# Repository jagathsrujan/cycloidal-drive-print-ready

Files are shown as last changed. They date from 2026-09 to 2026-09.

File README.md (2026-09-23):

# Cycloidal Drive — Print-Ready

A 15:1 cycloidal gearbox, cleaned up in FreeCAD and exported for 3D printing.
**106 printed parts across 15 part types**, plus the purchased hardware sorted out.

The design is the [HowToMechatronics DIY Cycloidal Drive](https://howtomechatronics.com/how-it-works/what-is-cycloidal-driver-designing-3d-printing-and-testing/)
(N = 16 ring pins, R = 45 mm, Rr = 6.5 mm, E = 1.5 mm). This repo is the print-prep pass
over that CAD: the original STEP is a single flat assembly of 216 objects with no indication
of what is printable, what you have to buy, or how many of each to make.

## How it works

An eccentric cam on the input shaft drives two cycloidal disks around the inside of a ring of
16 rollers. The disk has **one fewer lobe than there are rollers** — 15 lobes against 16 rollers —
so one full turn of the cam advances the disk by exactly one lobe. That single rule gives the
whole gear ratio:

```
ratio = N / (N - 1) = 16 / 15  ->  15:1 reduction
```

Two disks run 180° out of phase to cancel the imbalance the eccentric motion creates. The
reduced rotation leaves through 6 output pins passing through holes in both disks.

The design parameters, from the article:

| | |
|---|---|
| `N` rollers | 16 |
| `R` roller pitch radius | 45 mm |
| `Rr` roller radius | 6.5 mm |
| `E` eccentricity | 1.5 mm |
| Ratio | 15:1 |
| Envelope | Ø115 mm, 109 mm long including the NEMA 17 |

The disk profile is an epitrochoid, not a circle arc — `R/(E·N)` is what shapes the lobes, and
`E` must stay below half the roller diameter or the profile folds on itself. The roller "teeth"
are ball bearings rather than printed bushings; that substitution is the whole reason a printed
version of this gearbox survives at all.

Measured on the author's build: **260 N·cm out of the gearbox from a 26 N·cm NEMA 17** — about
10× torque multiplication, roughly 66 % efficiency. It is also back-drivable.

## What's here

| Path | What it is |
|---|---|
| `Cycloidal Drive - PRINT READY.FCStd` | cleaned FreeCAD model, parts grouped and named |
| `STL/01_PRINT_THESE/` | 15 folders, one per printed part, quantity in the folder name |
| `3MF_PRINT_READY/` | the whole drive as 5 ready-to-slice Bambu projects, P1S and H2D |
| `STL/PRINT_LIST.md` | print list, buy list, slicer settings |
| `BOM.md` | hardware buy list with prices, sources, and CAD fit checks |
| `ASSEMBLY.md` | build order, verified stack heights, and the gotchas |
| `Cycloidal Drive - 3D Printable DIY.STEP` | the original author's CAD, unmodified |

## Print it without slicing

`3MF_PRINT_READY/` carries the whole drive as Bambu Studio projects, split for a P1S and an H2D.
The split differs by machine, not by part: the H2D's bed takes the motor mount and coupler onto
its structural plate, so the same 106 parts make two projects there and three on the P1S.

| Project | Covers |
|---|---|
| `H2D_01_structural.3mf` | housing, lid, both disks, both output flanges, 4 shaft sections, motor mount, coupler |
| `H2D_02_smallparts.3mf` | 16 ring pins, 6 output pins, 32 × 7 mm + 16 × 3 mm spacers, 6 rings, 18 shims |
| `P1S_01_bigdiscs.3mf` | housing, lid, both disks, both output flanges |
| `P1S_02_shaftparts.3mf` | 4 shaft sections, motor mount, coupler |
| `P1S_03_smallparts.3mf` | the small parts, same 85 as the H2D's second plate |

They are unsliced, and the parts are **not arranged yet** — every object is stacked at the plate
centre, so the first thing to do after opening one is Arrange (or the model prints as a tower).
Nothing has a saved plate time either; slice once to get the real number.

What is already set is the profile, exactly what this repo asks for — **0.07 mm hole / 0.02 mm
contour expansion**, 0.2 mm layers, 5 walls, no supports, 50 % gyroid on the big parts and 100 %
grid with an auto brim on the small ones, Bambu PLA Basic on the High Temp plate. So skip the
calibration plate if you print these on a Bambu with that filament; calibrate if your setup differs.

## Print quantities

| Qty | Part | | Qty | Part |
|----:|---|-|----:|---|
| 1 | Roller Pins Housing | | 16 | Ring Pin Ø6×35 |
| 1 | Housing Lid | | 6 | Output Pin Ø6×15 |
| 2 | Cycloidal Disk | | 32 | Spacer 7 mm |
| 4 | Input Shaft (sections p1–p4) | | 16 | Spacer 3 mm |
| 1 | Output Flange Front (13 mm) | | 6 | Distance Ring 3×6 |
| 1 | Output Flange Rear (16 mm) | | 12 | Shim 1 mm × Ø6 |
| 1 | Motor Coupler | | 6 | Shim 1 mm × Ø15 |
| 1 | Motor Mount (NEMA 17) | | | |

## Buy these

44 × bearing 686-2RS (6×13×5) · 4 × 6802-2RS (15×24×5) · 2 × 6807-2RS (35×47×7) ·
1 × NEMA 17 stepper · M3/M4 bolts and heat-set threaded inserts — full quantities in
[`STL/PRINT_LIST.md`](STL/PRINT_LIST.md).

## Before you print

Not slicing it from the STLs? The `3MF_PRINT_READY/` projects already carry the settings below.

Set **Hole Horizontal Expansion ≈ 0.07 mm** in your slicer. Printed bores come out undersize,
and that setting is what makes the 13 mm and 24 mm bearing seats press-fit instead of either
loose or impossible. Calibrate on a test plate first.

The 16 ring pins are the only printed part taking real load. They print hollow with a 3 mm bore
on purpose — the article's build slid **3 mm metal shafts** through them, and Ø6 mm ground steel
dowel is a straight drop-in upgrade if you'd rather not print them at all. See
[`ASSEMBLY.md`](ASSEMBLY.md) for the build order and the fits that will bite you.

## Model structure

The FreeCAD file groups everything the way you'd work through it at the printer:

```
Cycloidal Drive - PRINT READY
├── 01_PRINT_THESE_3D          (15 groups, 106 parts — x{N}_{name})
└── 02_BUY_THESE_HARDWARE      (11 groups, 92 parts)
```

Geometry is untouched — every part sits exactly where it did in the original assembly, so
clearances and fits are unchanged. Only the organisation, names and visibility are new.

## Credit

Original design and CAD by [HowToMechatronics](https://howtomechatronics.com/how-it-works/what-is-cycloidal-driver-designing-3d-printing-and-testing/).
The STEP file is redistributed here unmodified for reference; check the original source for
its terms before reusing the CAD commercially.

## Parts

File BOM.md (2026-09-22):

# BOM — Hardware Buy List

Everything to buy for one complete gearbox (the 106 printed parts are not included — see
[`STL/PRINT_LIST.md`](STL/PRINT_LIST.md)). Prices in ₹, checked Sep 2026. **Every dimension
below was measured against `Cycloidal Drive - PRINT READY.FCStd`** — the hardware group and
every mating bore in the printed parts — so the sizes are known-good, not assumed.

## Order 1 — OnlyScrews (onlyscrews.in)

| Qty | Item | Unit ₹ | Line ₹ | Notes |
|----:|---|---:|---:|---|
| 44 | 686 ZZ bearing 6×13×5 | 26.00 | 1,144.00 | 32 ring rollers + 12 output-pin bearings. CAD: Ø6 bore / Ø13 OD / 5.00 wide, stack heights 27 and 15 mm — exact |
| 4 | M3×8 socket head SS304 DIN 912 | 3.20 | 12.80 | motor → mount. Mount has the 31×31 pattern, holes measured at exactly ±15.5 |
| 4 | M3×10 socket head SS304 DIN 912 | 3.20 | 12.80 | mount → housing. Housing holes measured at exactly the 63×26 rectangle (±31.5, ±13) |
| 6 | M3×20 button head SS304 * | 2.60 | 15.60 | output roller pins (span X 93–116 in CAD). *socket head is out of stock — button head fits; socket head ₹3.80 when restocked |
| 2 | M3×30 socket head SS304 DIN 912 | 6.00 | 12.00 | clamps the 4 input-shaft sections; threads into the 2 shaft inserts (X 87–120 measured) |
| 8 | M4×40 socket head SS304 DIN 912 | 7.60 | 60.80 | housing ↔ lid. Lid has Ø4 clearance + Ø7×4 head counterbore; 40 mm shank lands exactly on the insert |
| 9 | M3×5 brass heat-set insert (3D-printing slant knurled) | 4.60 | 41.40 | output face ×6 (Ø4×5 pockets), shaft back ×2, coupler ×1. OD 4.4 vs Ø4.0 holes = correct heat-set bite. **Use 5 mm, not 6 mm — the output-face pockets are exactly 5 deep** |
| 8 | M4×6 brass heat-set insert | 3.40 | 27.20 | housing back face. CAD pocket Ø5.6 × 5–6 deep; insert OD 5.8 × 6 → fits. **Do not buy the 8 mm version — it bottoms out and sticks out** |
| 16 | M3×35 hard dowel pin (3 mm metal shaft) | 6.40 | 102.40 | slides inside the printed hollow ring pins (bore Ø3.0 × 34.8 measured) |

**Subtotal ₹1,429.00** + 18 % GST at checkout. Free shipping over ₹799.
Coupon codes seen on site: `DEEZNUTS` 5 % over ₹849 · `SCREWME10` 10 % over ₹1,599 · `LOYALSCREWER` 15 % over ₹2,999.

## Order 2 — bearings + motor (OnlyScrews doesn't stock these)

| Qty | Item | Unit ₹ | Line ₹ | Source |
|----:|---|---:|---:|---|
| 4 | 6802 bearing 15×24×5 | 80.00 | 320.00 | IndiaMART — Manzil Trading, Mumbai. CAD: Ø15 journals on all 4 shaft sections, Ø24 bores in front flange + both disks + rear flange — exact |
| 2 | 6807 bearing 35×47×7 | 98.00 | 196.00 | IndiaMART — Manzil Trading, Mumbai. CAD: Ø47 × 7 seats in housing (X 85–92) and lid (119–126), Ø35 journals on both output flanges — exact |
| 1 | NEMA 17 stepper, 42-40 body, 4.2 kg-cm, Ø5 D-shaft | 549.00 | 549.00 | Amazon.in (alt: QuartzComponents ₹605). CAD mount = 31×31 + Ø22 pilot + Ø5 × 15 coupler bore — matches any standard 42-40 NEMA 17 |

**Subtotal ₹1,065.00** (IndiaMART prices typically +GST).

## Total

| | ₹ |
|---|---:|
| OnlyScrews (incl. 18 % GST) | 1,686 |
| Bearings (incl. 18 % GST) | 609 |
| Motor | 549 |
| **Total** | **≈ 2,845** |

Variants:
- Listed prices without GST: ₹2,497.
- All-online convenience route (Flipkart ZMS 6802 10-pack ₹1,499 + Amazon XERFU 6807 4-pack ₹400 instead of IndiaMART): ≈ ₹4,140.
- Optional spares (PRINT_LIST recommends): +4 × 686 bearing ≈ +₹123.

## CAD fit checks that mattered

- **686 / 6802 / 6807** measured bore-for-bore against the model: ring roller bores Ø13, output
  stack 1+5+3+5+1 = 15 mm, 6802 journals Ø15 / bores Ø24, 6807 seats Ø47 × 7 / journals Ø35.
  All exact. 686 ZZ vs the CAD's 686-2RS: same dimensions (shield vs seal), fine here.
- **M4/M3 insert lengths** were the one real trap: the CAD models the inserts as Ø5.6 × 5 (M4)
  and Ø4.0 × 5 (M3) in 5–6 mm deep pockets. Buy the 6 mm M4 and the 5 mm M3 — the longer
  versions from the first draft of this BOM would not seat.
- **Coupler insert pocket is Ø5.6** (larger than the insert) — a standard M3 heat-set insert
  sits loose there; add a drop of CA glue.
- **M3 bolts are DIN 912 socket heads** in the model (Ø5.5 head); SS304 socket heads from
  OnlyScrews are the same standard. The M3×20 button-head substitute only changes head height
  inside a counterbore that has clearance to spare.
- **3 mm shafts:** the ring pins print with a Ø3 bore and the CAD expects a 35 mm shaft — the
  M3×35 dowel pins are the OnlyScrews-friendly version of the article's "3 mm metal shaft".

## Links

- onlyscrews.in — [686 ZZ](https://onlyscrews.in/products/686-zz-deep-groove-ball-bearing-6x13x5) ·
  [M3 socket heads](https://onlyscrews.in/collections/socket-head-m3) ·
  [M4×40](https://onlyscrews.in/products/m4-x-40mm-hex-allen-socket-head-ss-304-screw-dia-4mm-length-40mm) ·
  [M3×5 inserts](https://onlyscrews.in/products/m3-x-5mm-3d-printing-brass-threaded-inserts-dia-3mm-length-5mm) ·
  [M4×6 inserts](https://onlyscrews.in/products/m4-x-6mm-brass-threaded-inserts) ·
  [M3×35 dowel pins](https://onlyscrews.in/products/m3-x-35mm-hard-dowel-pins-dia-3mm-length-35mm)
- [IndiaMART 6802 (Manzil Trading)](https://www.indiamart.com/proddetail/6802-zz-2rs-radial-deep-groove-ball-bearing-24685559033.html) ·
  [IndiaMART 6807](https://www.indiamart.com/proddetail/6807-zz-2rs-radial-deep-groove-ball-bearing-24685567673.html)
- [Amazon 6807 4-pack (alt)](https://www.amazon.in/XERFU-6807-ZZ-Pieces-Bearing/dp/B0HDR91JZ7) ·
  [Flipkart 6802 10-pack (alt)](https://www.flipkart.com/zms-6802-zz-10-piece-id-15mm-od-24mm-width-5mm-japanese-high-speed-ball-bearing-wheel/p/itm5518b389155b9) ·
  [QuartzComponents NEMA 17 (alt)](https://quartzcomponents.com/products/nema17-pr42hs40-1204af-02-4-2kgcm-stepper-motor-d-type-shaft)

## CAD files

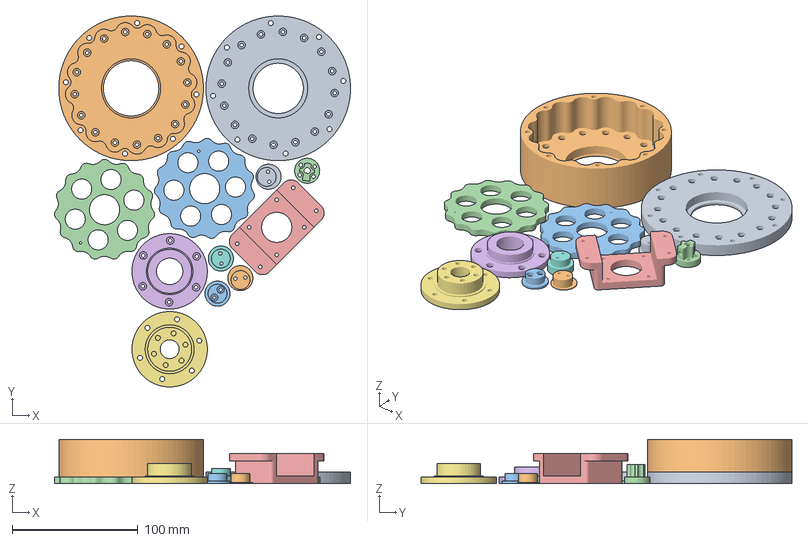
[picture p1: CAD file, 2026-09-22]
3MF_PRINT_READY/H2D_01_structural.3mf
235.2 x 294.8 x 35.0 mm
x1_Roller_Pins_Housing_LID__Housing_Lid.stl
x1_Roller_Pins_Housing__Roller_Pins_Housing.stl
x2_Cycloidal_Disk__Cycloidal_Disk_B.stl
x2_Cycloidal_Disk__Cycloidal_Disk_A.stl
x1_Motor_Mount__Motor_Mount.stl
x1_Output_Flange_Front__Output_Flange_Front.stl
x1_Output_Flange_Rear__Output_Flange_Rear.stl
x1_Input_Shaft_SET_4_pieces__Input_Shaft_p1.stl
x1_Input_Shaft_SET_4_pieces__Input_Shaft_p2.stl
x1_Input_Shaft_SET_4_pieces__Input_Shaft_p3.stl
x1_Input_Shaft_SET_4_pieces__Input_Shaft_p4.stl
x1_Motor_Coupler__Motor_Coupler.stl

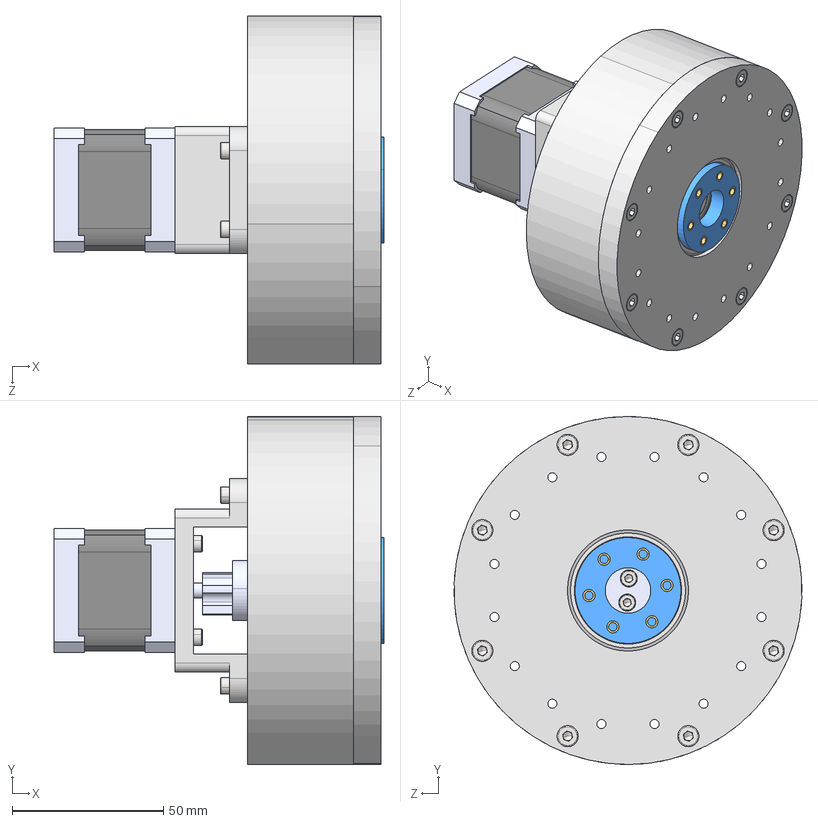
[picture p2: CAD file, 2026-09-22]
Cycloidal Drive - 3D Printable DIY.STEP
109.0 x 115.0 x 115.0 mm
Roller pins housing
6mm shaft for roller pins x 16
Spacer 6mm ID x 16
Ball Bearing- 6x13x5mm_Ball Bearing 608 - 8x22x7mm x 44
Spacer 6mm ID v3 x 16
Spacer 6mm ID v2 x 16
Stepper NEMA 17 - 20mm shaft r1_Stepper NEMA 17 - 20mm shaft
Cycloidal disk
Cycloidal disk 2
Output disk flange p1
Ball Bearing-35x47x7mm_Ball Bearing 608 - 8x22x7mm x 2
Roller pins housing lid
Output disk flange p2
6mm shaft for output roller pins x 6
Distance ring 1mm ID 6mm x 12
Distance ring 4mm ID 6mm x 6
DIN 912 M3 x 20 --- 20N_DIN 912 M3 x 20 --- 20N x 6
Threaded insert M4 - L5mm x 8
NEMA 17 motor mount
Input shaft - p1
Input shaft - p2
Input shaft - p3
Input shaft - p4
Distance ring 1mm ID 15mm x 6
Ball Bearing-15x24x5mm_Ball Bearing 608 - 8x22x7mm x 4
Nema 17 shaft coupler
EN ISO 4762 M4 x 40 - 20N_EN ISO 4762 M4 x 40 - 20N x 8
EN ISO 4762 M3 x 30 - 18N_EN ISO 4762 M3 x 30 - 18N x 2
EN ISO 4762 M3 x 10 - 10N_EN ISO 4762 M3 x 10 - 10N x 4
EN ISO 4762 M3 x 8 - 8N_EN ISO 4762 M3 x 8 - 8N x 4
Threaded insert M3 - L5mm x 9

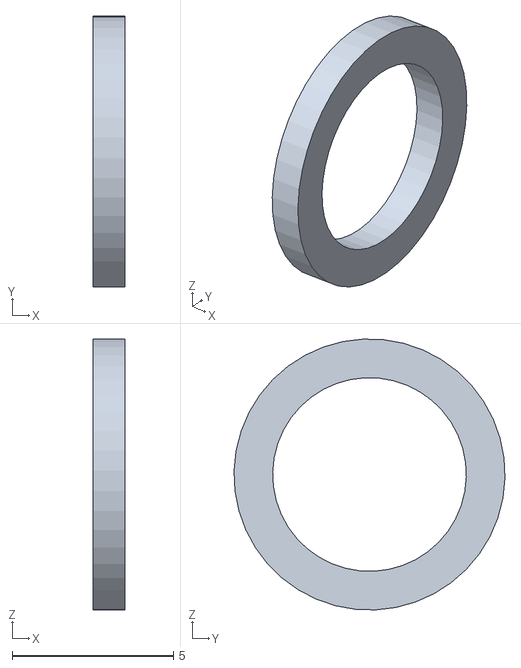
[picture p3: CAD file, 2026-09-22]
STL/01_PRINT_THESE/x12_Shim_1x6/Shim_1x6.stl
1.00 x 8.40 x 8.39

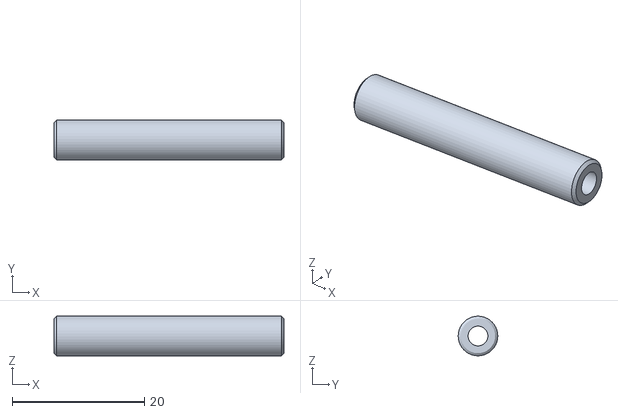
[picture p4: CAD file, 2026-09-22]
STL/01_PRINT_THESE/x16_Ring_Pin_6x35_hollow/Ring_Pin_6x35.stl
34.8 x 6.00 x 5.99

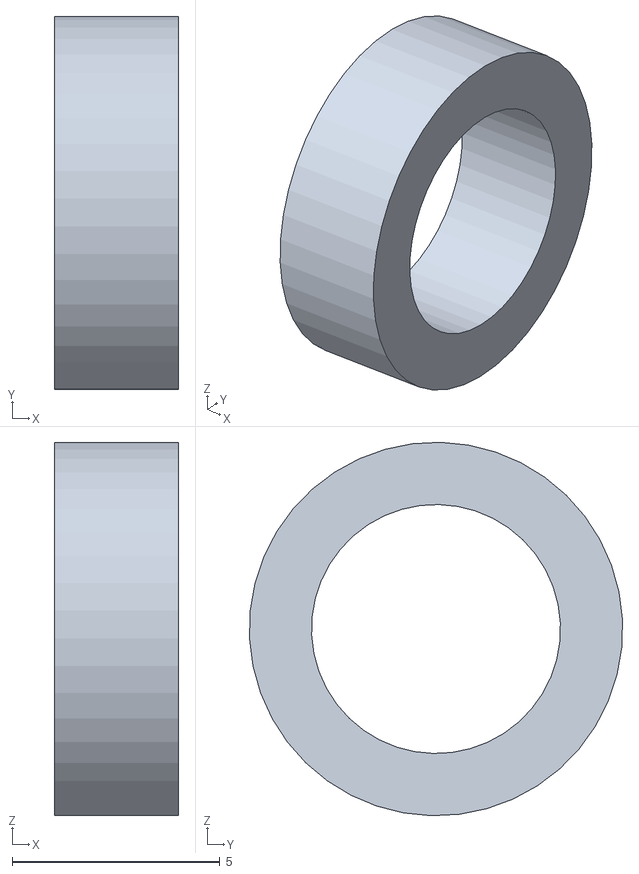
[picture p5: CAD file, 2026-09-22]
STL/01_PRINT_THESE/x16_Spacer_3mm/Spacer_3mm.stl
3.00 x 8.99 x 9.00

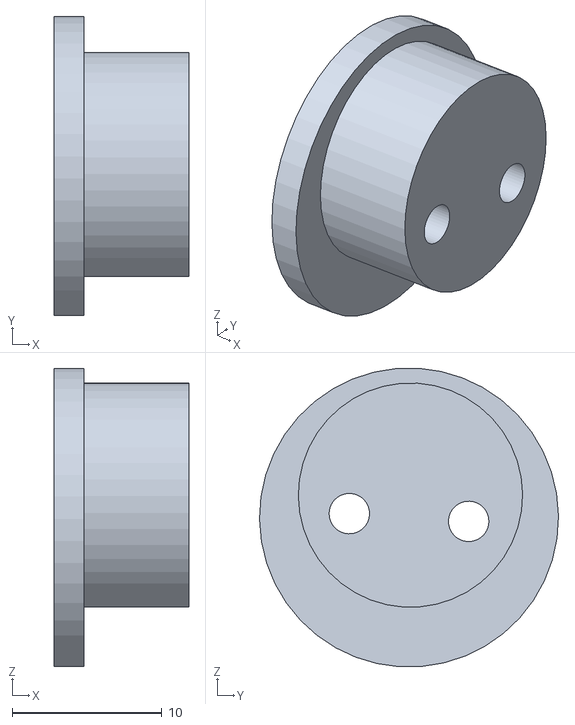
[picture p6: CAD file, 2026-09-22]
STL/01_PRINT_THESE/x1_Input_Shaft_SET_4_pieces/Input_Shaft_p2.stl
9.00 x 20.0 x 20.0

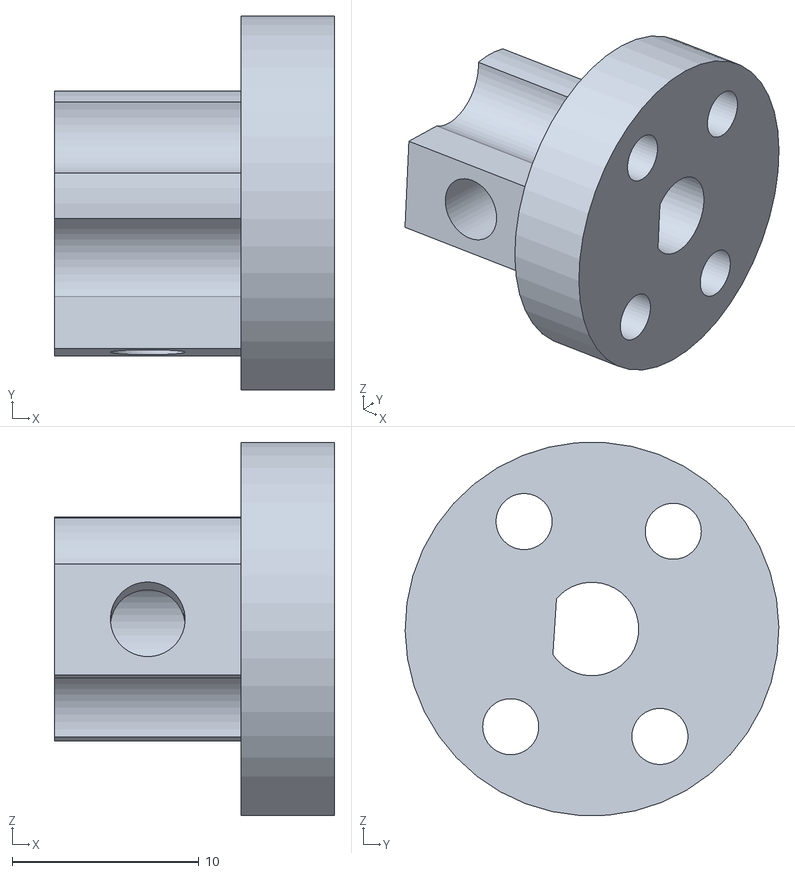
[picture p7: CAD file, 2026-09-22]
STL/01_PRINT_THESE/x1_Motor_Coupler/Motor_Coupler.stl
15.0 x 20.0 x 20.0

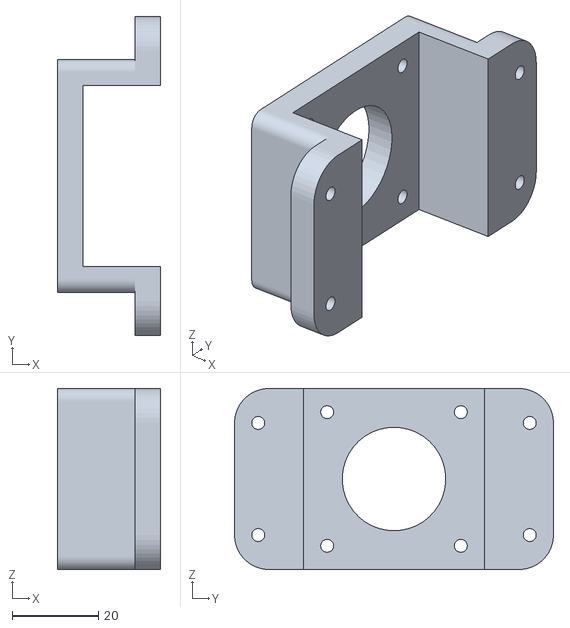
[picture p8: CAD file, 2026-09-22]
STL/01_PRINT_THESE/x1_Motor_Mount/Motor_Mount.stl
24.0 x 74.0 x 42.0

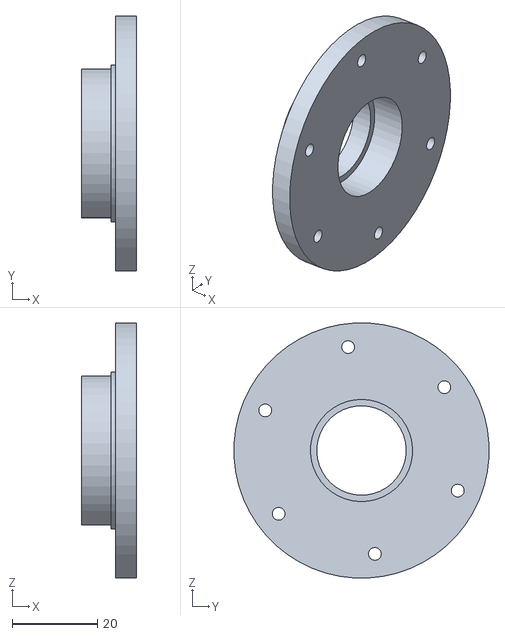
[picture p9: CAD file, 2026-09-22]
STL/01_PRINT_THESE/x1_Output_Flange_Front/Output_Flange_Front.stl
13.0 x 59.9 x 59.9

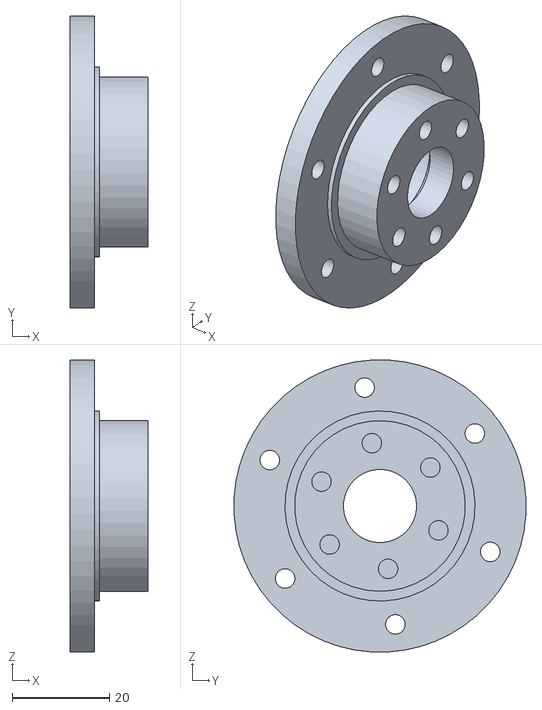
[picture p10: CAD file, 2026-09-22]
STL/01_PRINT_THESE/x1_Output_Flange_Rear/Output_Flange_Rear.stl
16.0 x 59.9 x 59.9

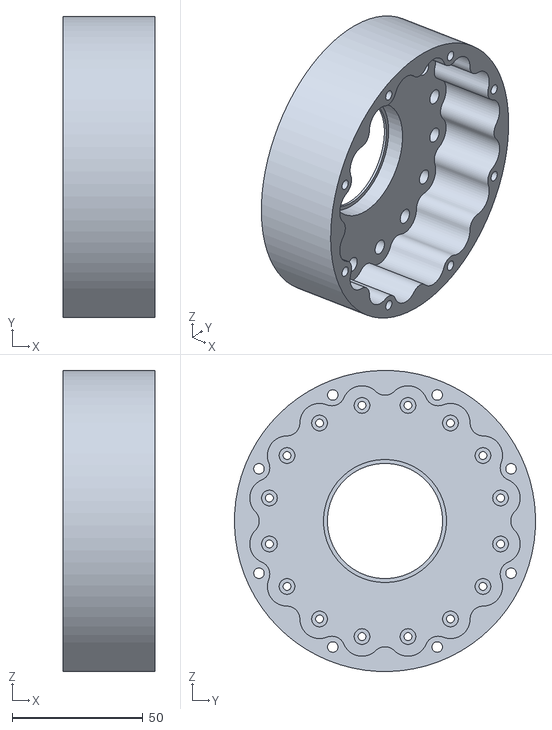
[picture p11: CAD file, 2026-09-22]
STL/01_PRINT_THESE/x1_Roller_Pins_Housing/Roller_Pins_Housing.stl
35.0 x 114.9 x 114.9

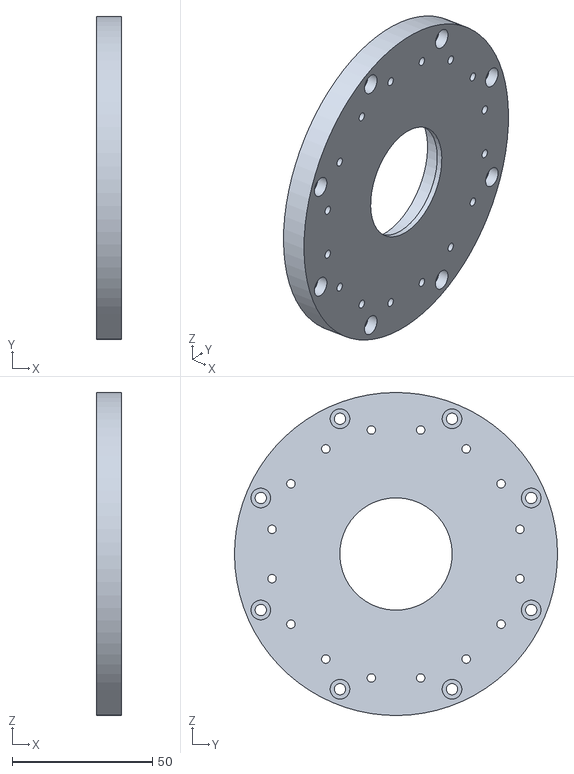
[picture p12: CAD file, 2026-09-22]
STL/01_PRINT_THESE/x1_Roller_Pins_Housing_LID/Housing_Lid.stl
9.00 x 115.0 x 115.0

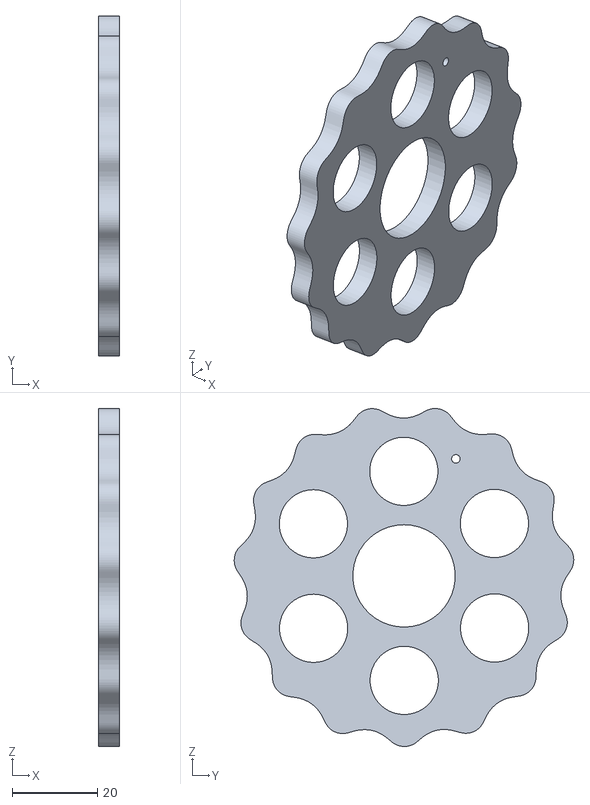
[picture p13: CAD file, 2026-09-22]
STL/01_PRINT_THESE/x2_Cycloidal_Disk/Cycloidal_Disk_B.stl
5.00 x 79.6 x 79.2

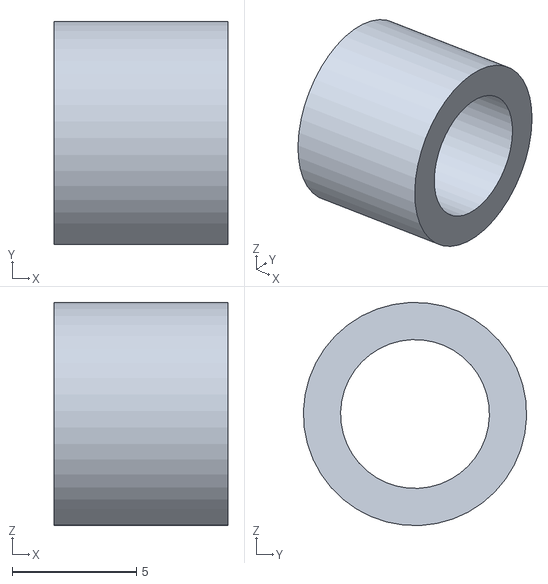
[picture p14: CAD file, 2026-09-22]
STL/01_PRINT_THESE/x32_Spacer_7mm/Spacer_7mm.stl
7.00 x 9.00 x 8.99

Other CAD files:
STL/01_PRINT_THESE/x6_Distance_Ring_3x6/Distance_Ring_3x6.stl
STL/01_PRINT_THESE/x6_Output_Pin_6x15_hollow/Output_Pin_6x15.stl
STL/01_PRINT_THESE/x6_Shim_1x15/Shim_1x15.stl
3MF_PRINT_READY/P1S_02_shaftparts.3mf
3MF_PRINT_READY/H2D_02_smallparts.3mf
3MF_PRINT_READY/P1S_01_bigdiscs.3mf
3MF_PRINT_READY/P1S_03_smallparts.3mf
Cycloidal Drive - PRINT READY.FCStd
STL/01_PRINT_THESE/x1_Input_Shaft_SET_4_pieces/Input_Shaft_p1.stl
STL/01_PRINT_THESE/x1_Input_Shaft_SET_4_pieces/Input_Shaft_p3.stl
STL/01_PRINT_THESE/x1_Input_Shaft_SET_4_pieces/Input_Shaft_p4.stl
STL/01_PRINT_THESE/x2_Cycloidal_Disk/Cycloidal_Disk_A.stl

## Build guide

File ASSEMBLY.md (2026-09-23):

# Assembly

Build order from the [HowToMechatronics article](https://howtomechatronics.com/how-it-works/what-is-cycloidal-driver-designing-3d-printing-and-testing/),
cross-checked against the CAD in this repo. Part names match the FreeCAD groups and the
folders in `STL/01_PRINT_THESE/`.

Axial measurements below are read straight out of the model — the X axis is the gearbox axis,
motor at the back (X=20), output face at the front (X=129).

## 0. Before anything else

- **Install all heat-set inserts first.** 8 × M4 (housing back face) and 9 × M3 — 6 on the
  front output face, 2 in the back of the input shaft, 1 in the motor coupler area.
  Once the gearbox is stacked you cannot reach them.
- Chase the 6 mm pin bores in the housing and lid. This is a tight build and every bore matters.
  The [`3MF_PRINT_READY/`](3MF_PRINT_READY/) projects pre-compensate the bores (0.07 mm hole /
  0.02 mm contour), so printing straight from those gets you there without slicer tuning.
- Test-fit a 686 bearing in a housing pin bore. Press fit, not hammer fit. If it's wrong, stop
  and fix your Hole Horizontal Expansion before printing the lid.

## 1. Ring gear — housing, pins, rollers

16 × `x16_Ring_Pin_6x35_hollow` go into the `x1_Roller_Pins_Housing`, then the rollers stack
onto each pin:

```
Spacer 7mm │ bearing │ Spacer 3mm │ bearing │ Spacer 7mm
```

That order is straight from the article, and the CAD agrees — measured spans on one pin column:

| Part | X span |
|---|---|
| Ring Pin Ø6×35 | 88.0 → 122.8 |
| Spacer 7 mm | 92.0 → 99.0 |
| Bearing 686 | 99.0 → 104.0 |
| Spacer 3 mm | 104.0 → 107.0 |
| Bearing 686 | 107.0 → 112.0 |
| Spacer 7 mm | 112.0 → 119.0 |

27 mm of roller stack centred in the 35 mm pin, so the pin sticks out both ends. The front end
seats into the lid — that's the tight fit when you close it up.

**About the pins:** they are printed hollow with a 3 mm bore for a reason. The author wasn't
confident a plain printed pin would survive the load, so he slid **3 mm metal shafts** down the
middle of each one. Either do that, or buy **Ø6 × 35 mm ground steel dowels** and skip the
printed pins entirely. Do *not* substitute M6 bolts — they measure under 6 mm, so the bearings
wobble on them.

## 2. Input shaft

`x1_Input_Shaft_SET_4_pieces` — four sections because the cam offset makes the shaft
impossible to assemble in one piece. Each section takes a 6802 bearing and distance rings.

- Slide the sections together on **2 × M3×30** bolts. Those holes are printed deliberately
  undersize so the bolts **cut their own thread** in the plastic — that's the design, not a
  mistake. Don't drill them out. They thread into the 2 M3 inserts at the back of the input shaft
  (both at the ±4 mm offset, X=103.5).
- The **cycloidal disks have to go on during this step**, not after. The author assembled the
  shaft first, then had to tear it back down because he couldn't get the disks in afterwards.

## 3. Output shaft

6 × `x6_Output_Pin_6x15_hollow`, each drilled through with an M3×20 bolt. Same idea as the ring
rollers, tighter stack — this one fills the full 15 mm pin with zero slack:

```
Shim 1mm │ bearing │ Ring 3mm │ bearing │ Shim 1mm
```

| Part | X span |
|---|---|
| Output Pin Ø6×15 | 98.0 → 113.0 |
| Shim 1 mm | 98.0 → 99.0 |
| Bearing 686 | 99.0 → 104.0 |
| Ring 3 mm | 104.0 → 107.0 |
| Bearing 686 | 107.0 → 112.0 |
| Shim 1 mm | 112.0 → 113.0 |
| M3×20 bolt | 93.0 → 116.0 |

## 4. Stack it into the housing

1. Press one **6807** bearing into the housing (X=88.5).
2. Lower the input + output assembly in.
3. Press the second **6807** in at the front (X=122.5).

**Disk phasing:** the two cycloidal disks sit 8 mm apart and must be **180° out of phase**. The
author put small index holes in both disks, 180° apart, so you just line them up and push the
output rollers through. Find those holes before you start — you cannot see the phase once the
disks are inside the ring.

## 5. Lid, motor mount, motor

- **Lid:** goes over all 16 pins, tight fit — expect to need some force.
- **8 × M4×40** through the lid into the M4 inserts in the back of the housing. The bolt spans
  X 84 → 128, i.e. the full housing (84→119) plus lid (119→128).
- **Motor mount:** 4 × M3×10 at X=81.5, on a 63 × 26 mm rectangle — mount to housing.
- **Motor:** 4 × M3×8 at X=63.5, on a 31 × 31 mm square — that's the standard NEMA 17 pattern.
- **Coupler:** slides over the motor shaft and bolts to the M3 inserts at the back of the input shaft.

## Gotchas worth knowing before you start

- **Don't skip the calibration plate.** 0.07 mm of Hole Horizontal Expansion is the difference
  between "press fit" and "won't go on". This gearbox is essentially a stack of fits.
- **Disks must be phased 180°** using the index holes, or the gearbox will fight itself.
- **The disks have to go on with the input shaft**, mid-assembly (see step 2).
- **Ring pins are the weak point.** Printed solid in PLA they can shear under shock; the 3 mm
  rod or steel dowel fix exists for exactly this reason.
- This thing is **back-drivable** — turning the output turns the motor.

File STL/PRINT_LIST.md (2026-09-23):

# PRINT LIST — Cycloidal Drive 15:1

From `Cycloidal Drive - 3D Printable DIY.STEP` (HowToMechatronics 15:1, N=16, R=45, Rr=6.5, E=1.5).
Cleaned model: **`Cycloidal Drive - PRINT READY.FCStd`** → group `01_PRINT_THESE_3D`.

Each folder under `01_PRINT_THESE/` is one part type; the folder name carries the quantity to print.
STLs are in **assembly orientation** — lay them flat in the slicer (see notes at the bottom).

## Print these — 106 parts across 15 folders

| Qty | Folder | Files | Notes |
|----:|---|---|---|
| 1 | `x1_Roller_Pins_Housing` | `Roller_Pins_Housing.stl` | ring gear; print flat, pin bores vertical |
| 1 | `x1_Roller_Pins_Housing_LID` | `Housing_Lid.stl` | print flat; 16 pin slots must line up |
| 2 | `x2_Cycloidal_Disk` | `Cycloidal_Disk_A.stl`, `_B.stl` | the two files are the same disk within 0.1% — print 2 of either, mount 180° apart |
| 4 | `x1_Input_Shaft_SET_4_pieces` | `Input_Shaft_p1..p4.stl` | 4 different sections = one set; axis vertical if possible |
| 1 | `x1_Output_Flange_Front` | `Output_Flange_Front.stl` | 13 mm thick; print flat, pin holes vertical |
| 1 | `x1_Output_Flange_Rear` | `Output_Flange_Rear.stl` | 16 mm thick |
| 1 | `x1_Motor_Coupler` | `Motor_Coupler.stl` | match your motor's shaft flat |
| 1 | `x1_Motor_Mount` | `Motor_Mount.stl` | NEMA 17 bracket |
| 16 | `x16_Ring_Pin_6x35_hollow` | `Ring_Pin_6x35.stl` | Ø6×35, 3 mm bore; **or buy 6×35 mm steel dowels** |
| 6 | `x6_Output_Pin_6x15_hollow` | `Output_Pin_6x15.stl` | Ø6×15, 3 mm bore takes the M3×20 bolt |
| 32 | `x32_Spacer_7mm` | `Spacer_7mm.stl` | ring rollers: 7 / bearing / 3 / bearing / 7 |
| 16 | `x16_Spacer_3mm` | `Spacer_3mm.stl` | |
| 6 | `x6_Distance_Ring_3x6` | `Distance_Ring_3x6.stl` | output pin stack |
| 12 | `x12_Shim_1x6` | `Shim_1x6.stl` | output pins, 2 per pin |
| 6 | `x6_Shim_1x15` | `Shim_1x15.stl` | input shaft bearings |

106 printed parts total. The 16 ring pins are the only printed part carrying real load, and they
print hollow for a reason — see below.

## Buy these — do not print

| Qty | Part |
|----:|---|
| 1 | NEMA 17 stepper motor |
| 44 | Ball bearing 686-2RS — 6×13×5 mm (16 ring positions ×2, + 6 output pins ×2) |
| 4 | Ball bearing 6802-2RS — 15×24×5 mm |
| 2 | Ball bearing 6807-2RS — 35×47×7 mm |
| 16 | **3 mm metal shaft, 35 mm long** — slides inside the printed ring pins (optional if you use Ø6 dowels) |
| 8 | Bolt M4×40 (housing ↔ lid) |
| 6 | Bolt M3×20 (output roller pins) |
| 2 | Bolt M3×30 (clamps the 4 input-shaft sections) |
| 4 | Bolt M3×10 (motor mount ↔ housing) |
| 4 | Bolt M3×8 (motor ↔ mount, NEMA 17 pattern) |
| 8 | Threaded insert M4 (heat-set, housing back) |
| 9 | Threaded insert M3 (heat-set, 6 front output face + 2 input shaft + 1 coupler) |

Buy spares of the 686 bearings — 44 identical small parts, some will be gritty.
Prices, sources and the CAD-measured insert lengths: [`../BOM.md`](../BOM.md).

**The hollow pins:** the author wasn't confident a solid printed pin would survive the ring
load, so he made them hollow and slid 3 mm steel shaft down the middle of each — that's why
every pin in this model has a 3 mm bore. Either do that, or skip the printed pins entirely and
buy 16 × Ø6 × 35 mm ground steel dowels. Do not substitute M6 bolts; they measure under 6 mm
and the bearings will wobble on them.

Build order, stack heights and the fits that will bite you: [`../ASSEMBLY.md`](../ASSEMBLY.md).

## Slicer settings that matter

Already baked into [`../3MF_PRINT_READY/`](../3MF_PRINT_READY/) if you're printing on a Bambu.

- **Hole Horizontal Expansion ≈ 0.07 mm** and **Horizontal Expansion ≈ 0.02 mm**. Printed holes
  come out undersize; this is what turns the bearing bores into press fits. Calibrate on a test
  plate with Ø6.0 / Ø13.0 / Ø16.0 holes before committing to the housing.
- 0.15–0.2 mm layers, 4–5 walls, 40–60 % gyroid or cubic infill for housing, lid, disks, flanges.
  100 % for the pins and spacers — they are small.
- PLA is fine for a demo; PETG/ASA lasts longer under load. Heat is what kills printed cycloidal
  drives, so keep the disks cool and use light grease.
- Orientation: disks flat on the bed (no supports), housing and lid flat with pin bores vertical,
  input shaft sections axis-vertical, flanges flat with pin holes vertical.

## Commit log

2026-09-22 Print-ready cycloidal drive: 106 parts grouped into 15 STL folders
    Cleaned up the HowToMechatronics 15:1 cycloidal drive CAD for printing.
    The source STEP is a flat assembly of 216 objects with no indication of
    what is printable, what must be bought, or how many of each to make.
    FreeCAD model (Cycloidal Drive - PRINT READY.FCStd):
    - 01_PRINT_THESE_3D: 15 groups, 106 parts, named x{N}_{part}
    - 02_BUY_THESE_HARDWARE: 11 groups, 92 parts
    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
    [Cycloidal Drive - 3D Printable DIY.STEP, Cycloidal Drive - PRINT READY.FCStd, Cycloidal_Disk_A.stl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]
2026-09-22 Add assembly guide; document design, working principle and the 3 mm pin shafts
    Read the source article and filled in what the print files were missing:
    how the thing actually goes together, and what it is.
    ASSEMBLY.md (new)
    - build order in five stages with our group names and quantities
    - measured axial stack spans pulled from the CAD, confirming the
    article's 7/bearing/3/bearing/7 ring-roller order and the
    1/bearing/3/bearing/1 output stack
    - bolt map verified by position: M4x40 spans housing+lid (X84-128),
    M3x10 = 63x26 mount pattern, M3x8 = 31x31 NEMA 17 pattern,
    M3x30 threads into the two input-shaft inserts
    - the gotchas: disks must go on mid-assembly, 180 degree phasing via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
2026-09-22 Add hardware BOM with prices, sources and CAD-verified fit checks
    Buy list for the non-printed parts: one OnlyScrews order (686 bearings,
    M3/M4 bolts, heat-set inserts, 3 mm pin shafts) plus 6802/6807 bearings and
    the NEMA 17 from other retailers, totalling about Rs 2,845 incl. GST.
    Every dimension was measured against the CAD model's hardware group and its
    mating bores. The insert lengths are corrected to the modelled pockets
    (M4: 5.6 x 5 mm, M3: 4.0 x 5 mm) - the longer 8 mm/6 mm versions would not
    seat.
2026-09-22 Add print-ready 3MF projects for Bambu P1S and H2D
    Five OrcaSlicer project files covering all 106 parts: P1S in three plates
    (big discs / shaft parts / small parts), H2D in two plates (structural /
    small parts). Bambu PLA Basic at 0.2 mm layers, hole expansion 0.07,
    5 walls, 50% gyroid on structural parts and 100% infill on the smalls.
    Each plate was re-loaded and sliced cleanly in OrcaSlicer 2.4.2.
    [H2D_01_structural.3mf, H2D_02_smallparts.3mf, P1S_01_bigdiscs.3mf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]
2026-09-23 Document the 3MF print projects and the hardware BOM
    The 3MF projects and BOM.md landed on GitHub but stayed invisible in the docs.
    - README: list 3MF_PRINT_READY/ and BOM.md in "What's here"
    - README: new "Print it without slicing" section — the P1S/H2D plate split
    and the baked-in profile (0.07 mm hole / 0.02 mm contour, verified against
    each project's project_settings.config)
    - PRINT_LIST and ASSEMBLY: point at the 3MF projects and own up to the
    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
2026-09-23 Correct the 3MF section: parts are not arranged on the plates
    Inspected the projects' internals: every component in all five sits at
    XY (0,0), stacked into a tower (P1S bigdiscs spans Z 0-75 mm), and the
    plate metadata is empty. They were saved unsliced and unarranged, so
    they need an Arrange pass, and no print time is stored anywhere.
